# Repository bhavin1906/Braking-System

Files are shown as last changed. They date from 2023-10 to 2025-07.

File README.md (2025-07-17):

# Braking-System
Contributed to the end-to-end development of a Formula Student race car, fully built from scratch in the Team V_locity workshop through extensive design–manufacture–test cycles 

Led the Brakes Department, overseeing system design, component selection, force and thermal calculations, and performance modeling for optimal stopping efficiency under rulebook constraints 

Designed a dual-circuit hydraulic braking system with front–rear biasing, conducted deceleration modeling, brake force distribution analysis, and clamping pressure validation to meet safety-critical standards 

Supervised the manufacture of drilled rotors and caliper assemblies, ensuring reliable water and debris dispersion while maintaining thermal integrity under repeated stress cycles 

Coordinated cross-departmental design integration, working closely with Suspension, Steering, and Ergonomics teams to align brake packaging with upright geometry and ensure seamless mechanical interfacing 

Implemented component-level FEA (Ansys) to verify pedal deflection, disc thermal loads, and mounting stress paths under extreme race conditions 

Managed training programs for junior team members and recruited new talent, organizing multiple hands-on sessions on braking fundamentals, system design, and testing workflows 

Oversaw rigorous testing protocols for every subsystem of the car, ensuring full compliance with Formula Bharat regulations and continuous design iteration based on test data 

Collaborated on chassis–brake–suspension triangulation, optimizing weight distribution and minimizing CG height while balancing driver accessibility and safety envelope 

Participated in core manufacturing processes including arc welding of the AISI 1018 steel chassis, machining of wishbones and knuckles, and hydraulic line routing, gaining firsthand experience in applied fabrication

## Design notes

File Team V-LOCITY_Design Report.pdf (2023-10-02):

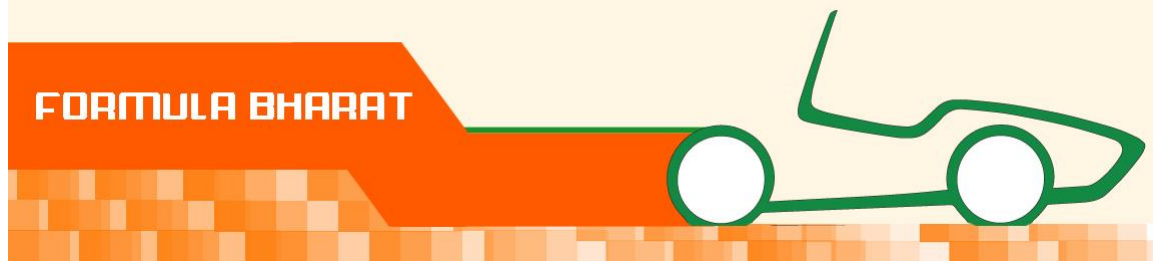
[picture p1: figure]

# FORMULA BHARAT

2021

# DESIGN REPORT

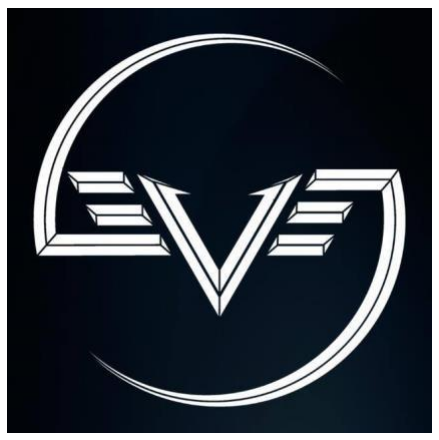
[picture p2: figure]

Team ID | : | 96
Team Name | : | Team V-LOCITY
College Name : | Visvesvaraya National Institute Of
| | Technology
City | : | Nagpur, Maharashtra
Report Author | : | Aishwarya Zawar
Report Co-Author : | Tanmay Kansal

INTRODUCTION

This design report is submitted by Team V-locity from VNIT, Nagpur. Visvesvaraya National Institute of Technology (VNIT) is located in Nagpur and is one of the 31 NITs in the country. The environment in the college coupled with interest of students in automobiles led to the creation of Team V-locity in 2009. Since then the team has been regularly participating in SAE events. The goal of 2021 for Team V-locity, VNIT Nagpur is to design and fabricate a vehicle which embodies innovation and elegance, while ensuring safety. The team was divided into departments, each responsible for the design and the manufacturing of the subassemblies of the vehicle, and the management team for the sponsorship and managerial activities. This report diagnoses the attributes of the vehicle subassemblies, highlighting the considerations, functions and processes behind their design.

Design goals:

The primary goal that was kept in mind while designing was to build a car for the weekend racing event which would have a simple yet innovative structure with optimum space utilization and using simple yet standard manufacturing methods for the manufacturing of the car.

The team having previously participated in SAE Supra 2019, comprehensively scrutinized the previous designs and addressed the grey areas. The suspension system was redesigned and optimized to increase the stiffness and also improve the overall drivability of the car. We have tried to achieve a low center of gravity as well as centralized weight distribution with the placement of components. The components were so placed that be conducive to the driver for ease of access to all the components for future customization and repair. Thus, we were able to come up with a design that would be simple yet efficient and conducive to the weekend racing event.

CHASSIS:

a) Material used-
1. AISI 1018 steel tubes
Reasons-
1. Light weight 2. Cheap 3. Good strength 4. Excellent weldability b) Type of welding-

Arc welding

### 1. Dimensions of members-

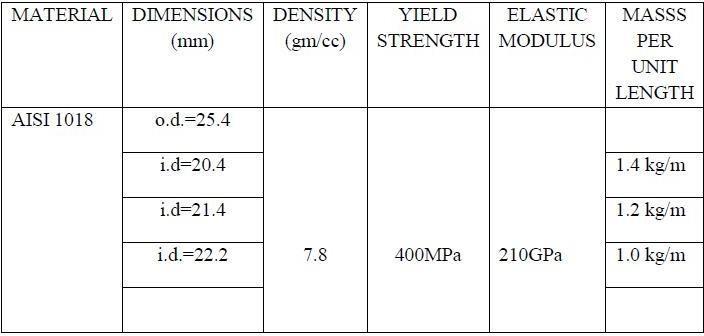
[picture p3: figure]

Rules from rulebook-

1. T2.3 Wheelbase- The car must have a wheelbase of at least 1525 mm (60 inches). The wheelbase is measured from the center of ground contact of the front and rear tires with the wheels pointed straight ahead.

2. Main Hoop- T3.11.4 In the side view of the vehicle, the portion of the Main Roll Hoop that lies above it attachment point to the Major Structure of the Frame must be within ten degrees (10°) of the vertical.
3. T3.11.6 In the front view of the vehicle, the vertical members of the Main Hoop must be at least 380 mm (15 inch) apart (inside dimension) at the location where the Main Hoop is attached to the Major Structure of the Frame.
4. Front Hoop- T3.12.4 The top-most surface of the Front Hoop must be no lower than the top of the steering wheel in any angular position.
5. T3.12.5 The Front Hoop must be no more than 250 mms (9.8 inches) forward of the steering wheel. This distance shall be measured horizontally, on the vehicle centerline, from the rear surface of the Front Hoop to the forward most surface of the steering wheel rim with the steering in the straight-ahead position.
6. T3.12.6 In side view, no part of the Front Hoop can be inclined at more than twenty degrees (20°) from
the vertical.
7. MAIN HOOP BRACING- T3.13.2 The Main Hoop must be supported by two braces extending in the forward or rearward direction on both the left and right sides of the Main Hoop.
8. T3.13.4 The Main Hoop braces must be attached as near as possible to the top of the Main

Hoop but not more than 160 mm (6.3 in) below the top-most surface of the Main Hoop. The included angle formed by the Main Hoop and the Main Hoop braces must be at least thirty degrees (30°).

9. FRONT HOOP BRACING- T3.14.2 The Front Hoop must be supported by two braces extending in the forward direction on both the left and right sides of the Front Hoop.

Side Impact Structural member must connect the Main Hoop and the Front Hoop. With a 77kg (170 pound) driver seated in the normal driving position all of the member must be at a height between 300 mm (11.8 inches) and 350 mm (13.8 inches) COCKPIT- 21. T4.1 Cockpit Opening 22. T4.1.1 In order to ensure that the opening giving access to the cockpit is of adequate size, a template shown in Figure 8 will be inserted into the cockpit opening. It will be held horizontally and inserted vertically until it has passed below the top bar of the Side Impact Structure (or until it is 350 mm (13.8 inches) above the ground for monocoque cars). No fore and aft translation of the template will be permitted during insertion. e) Static and Dynamic Analysis of Roll Cage-

10. T3.14.3 The Front Hoop braces must be constructed such that they protect the driver's legs and should extend to the structure in front of the driver's feet.
11. T3.14.4 The Front Hoop braces must be attached as near as possible to the top of the Front Hoop but not more than 50.8 mm (2 in) below the top-most surface of the Front Hoop.
12. OTHER SIDE TUBE RECQUIREMENT- T3.16 -Other Side Tube Requirements If there is a Roll Hoop brace or other frame tube alongside the driver, at the height of the neck of any of the team's drivers, a metal tube or piece of sheet metal must be firmly attached to the Frame to prevent the drivers' shoulders from passing under the roll hoop brace or frame tube, and his/her neck contacting this brace or tube.
13. Frontal Impact Structure- T3.18.1 The driver's feet and legs must be completely contained within the Major Structure of the Frame. While the driver's feet are touching the pedals, in side and front views no part of the driver's feet or legs can extend above or outside of the Major Structure of the Frame.
14. T3.18.2 Forward of the Front Bulkhead must be an energy-absorbing Impact Attenuator.
15. BULKHEAD- T3.19.2 Except as allowed by T3.19.3, The Front Bulkhead must be located forward of all noncrushable objects, e.g. batteries, master cylinders, hydraulic reservoirs.

16. T3.19.3 The Front Bulkhead must be located such that the soles of the driver's feet, when touching but not applying the pedals, are rearward of the bulkhead plane. (This plane is defined by the forward-most surface of the tubing.) Adjustable pedals must be in the forward most position.

BODYWORK

17. T3.24.1 Sharp edges on the forward-facing bodywork or other protruding components are prohibited.
18. T3.24.2 All forward facing edges on the bodywork that could impact people, e.g. the nose, must have forward facing radii of at least 38 mm (1.5 inches). This minimum radius must extend to at least forty-five degrees (45°) relative to the forward direction, along the top, sides and bottom of all affected edges.
19. T3.25.1 The Side Impact Structure for tube frame cars must be comprised of at least three (3) tubular members located on each side of the driver while seated in the normal driving position
20. T3.25.3 The locations Initial speed of the car = 60 Km/hr.=16.67 m/s

K.E. of the vehicle = .5* (300 Kgs) * sqr.(16.67 m/s)

Total crush energy = .5*(300Kgs)*sqr.(7 m/s) = 7350 J

Net energy after the attenuator has been crashed = 34333.33J

Velocity after crush - KE net = .5*m*sqr.(v)

Thus v= √ (2 KE net/m) = 15.129 m/s.

Assuming time taken for the car to come to rest after crush is .4 sec, deceleration = v/t = 4*g

{Standard value used while designing cars}

Assuming final mass of car = 300 kg, total force = 300*4*g = 11.77 kN

For Optimum testing of design taking,

Factor of Safety = 1.7

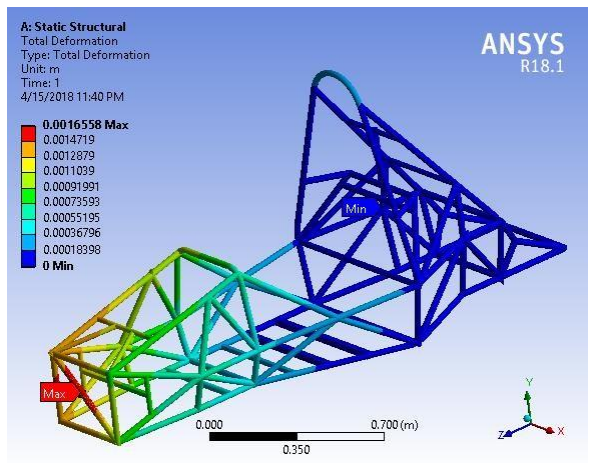
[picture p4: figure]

Force F = 20000 N

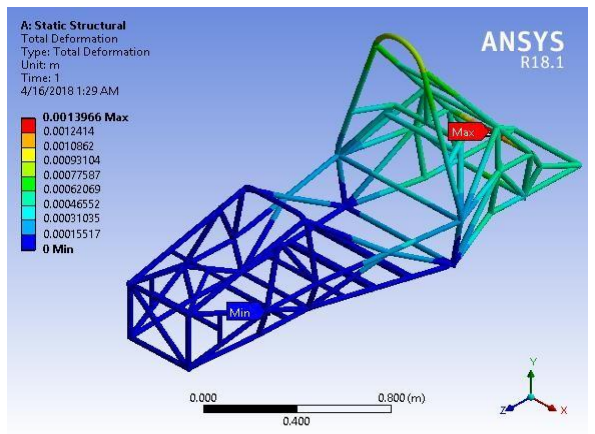
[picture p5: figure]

1.Front Impact : | 2. Rear Impact:

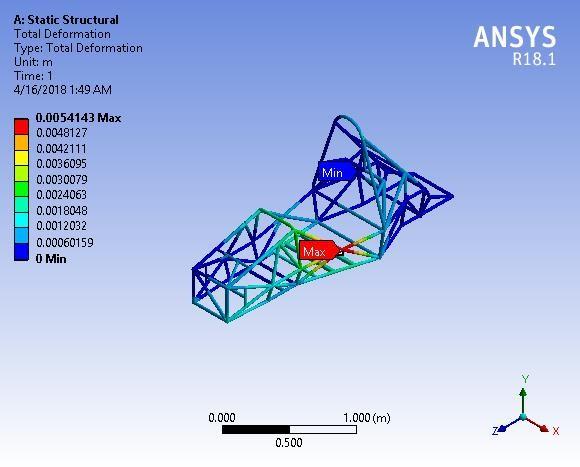
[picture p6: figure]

### 3. Side Impact:

SUSPENSION system:

Type of Suspension - Pushrod Suspension

Pushrod suspension gives more stiffness to our vehicle than previous type of suspension (McPherson strut) used in our last vehicle.
The suspension was designed to reduce the sprung mass, give stable characteristics such as camber change, roll centre and to minimize bump steer. For this, the last year’s suspension was analysed. We were able to save weight in knuckle, adapter plate and wishbone arms. The push-rod system is used, which allows us to change spring constant if necessary and also solves the problem of buckling which occurs in the case of simple spring system. The toes and camber of vehicles is kept to zero. Kingpin angle of 5 degrees is provided by structure of upright.
The team followed the following process steps:
a) Wheel selection
b) Tire selection
c) Wheelbase and track selection
d) Ground clearance optimization
e) Roll center optimization
f) Steering consideration
g) Braking considerations
h) All forces considerations
i) Packaging
Short long arm suspension geometry was used which helped us to minimize camber change. It also helped us in optimizing roll center height and keeping it almost at the same location with respect to car. Roll centre height was calculated considering, under-steer, non- toppling condition and reduction in scrub, using following formula. R*t = F*(roll center-center of mass) R= weight transfer due to roll
Track width rear= 1200mm
Track width front= 1300mm
Fc = Centrifugal Force= 0.7mg
Also change in roll center height is kept small so that roll properties of the vehicle do not change drastically under rolling condition. According to these roll center calculations, four bar chains were sketched for front and rear suspension. Force analysis of the four-bar chain was carried out by applying maximum reaction force on the knuckle, F= 1428N for front & F= 1668N for rear.
Using this force analysis, forces in the pull-rods were calculated. Using this pull-rod force and spring stiffness, k=45000 N/m (Bajaj avenger), bell cranks were designed (Arm ratio: 6:8 (for front suspension) and 6.5:10 (for rear suspension)) . Knuckle was designed with mountings for wishbones, tie rod, and brake caliper & brake adaptor plate. We also took care of packaging because it is a part which contributes to most of air drag by suspension components and weight. It was then analyzed with following forces-
1. Reaction force due to weight of car: Front= 941.4N , Rear= 1412.6 N
2. Braking torque= 100 N.m
3. Force due to acceleration= 507.1N
Wishbones were designed to keep the stresses under maximum stress value= 157.4 MPa, considering factor of safety, welding and stress reversal factor.

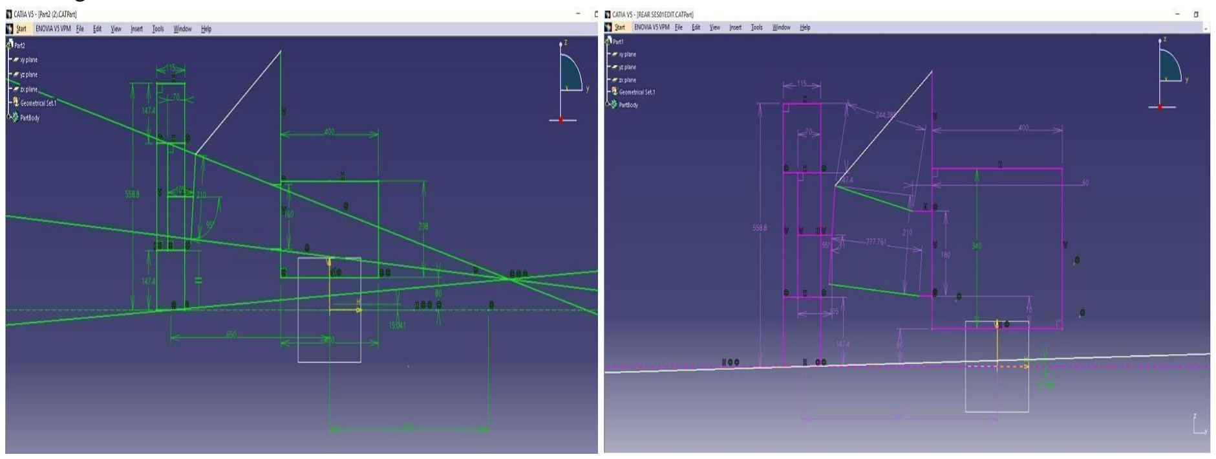
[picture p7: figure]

Front Suspension Calculations X= Force through upper wishbone
Y= Force through pushrod
Z= Force through lower wishbone
FC = Centrifugal Force | = 1318.46 N
R = Reaction Force by ground = 941.4 N
Bell Crank Ratio - Pushrod : Spring = 6:8
Applying Force and Moment Balance,
X*sin(13.4) + Y*sin(40) + Z*sin(4.32) = 941.4 N
-X*cos(13.4) + Y*cos(40) - Z*cos(4.32) = 1318.46 N
X*cos(13.4)*(0.411) + Z*cos(4.32)*(0.147) - Y*cos(40)*(0.384) + Y*sin(40)*(0.044) = 0 Solving these equations, we obtain
X = 500.2 N
Y = 1366.68 N
Z = -759.89 N
Therefore, Force transmitted through spring = 1366.68 * (6/8) N= 1025.01 N Deflection required in the spring for that force = 5 cm
Therefore Spring Constant (k) = 1025.01/0.05= 20502 N/m
We have used a spring having spring constant 45000N/m
So, Factor of Safety = 45000/ 20502= 2.19

Rear Suspension Calculations
X= Force through upper wishbone
Y= Force through pushrod
Z= Force through lower wishbone
FC = Centrifugal Force | = 1977.69 N
R = Reaction Force by ground = 1412.64 N Bell Crank Ratio - Pushrod : Spring = 6.5:10 Applying Force and Moment Balance,

X*sin(12.765) + Y*sin(47.6) + Z*sin(5.122) = -1977.69 N
X*cos(12.765) + Y*cos(47.6) - Z*cos(5.122) = 1412.64 N
X*cos(12.765)*(0.384) + X*sin(12.765)*(0.044) + Z*cos(5.12)*(0.147) + Z*sin(5.122)*(0.025) - Y*cos(47.6)*(0.384) + Y*sin(47.6)*(0.044) = 0
Solving these equations, we obtain
X = 2100.53 N, Y = 1639.03 N , Z = -2932.81 N
Therefore, Force transmitted through spring = 1639.03 * (6.5/10) N = 1065.369 N Deflection required in the spring for that force = 5 cm
Therefore, Spring Constant (k) = 1065.369/0.05 = 21307 N/m
We have used a spring having spring constant 45000N/m
So, Factor of Safety = 45000/ 21307 = 2.11

Wheel Assembly:

WHEELS AND TYRES

Tire selection is always a critical issue in race car. This year we are keeping same tire and alloy wheels used in former car. Reasons are, 145 width tires are sufficiently wider to give traction for a car having 37 bhp engine. For such engine cars large width tires reduce the fuel economy of the car along with increase in frictional and rolling resistance. Large tires and alloy wheels increases the car weight largely due to the reinforcement in rims. Also, considering rain chances on race track, we are keeping treaded tires instead

of slick tires. Further low width and treaded tires are ideal for front wheels for better steering maneuverability. Treads reduce the tire slip angle and hence Ackermann geometry closely holds the real steering geometry.

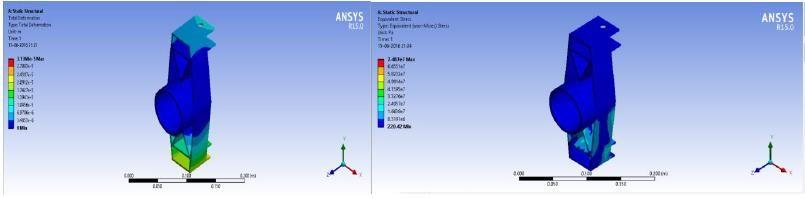
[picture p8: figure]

Upright Analysis

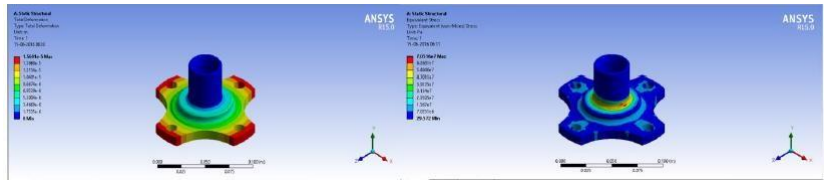
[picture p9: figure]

Hub Analysis

STEERING system:

Rack and Pinion steering system has been chosen over other steering systems for its compactness and ease of adjustment in Ackermann. The minimum width of the autocross track has been specified to be 3.5m and the outside diameter of the sharpest turn is 9m. Using these values, the calculations on SOLIDWORKS gave the angles of the front wheels to produce no scrub to be 39.81° for inner wheel and 27.24° for outer wheel. (fig)

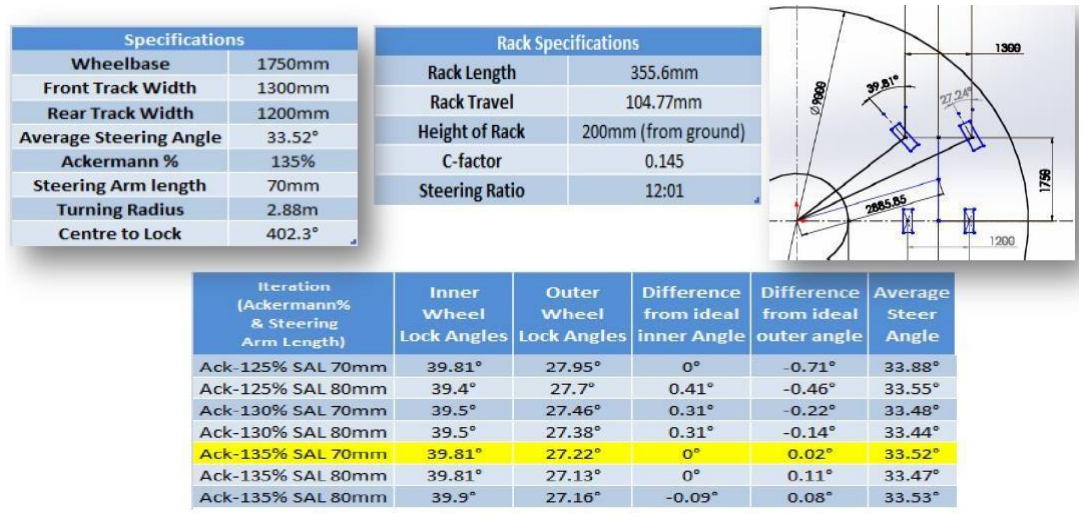
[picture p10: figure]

- From the above iterations, simulated on CATIA, at 135% Ackermann and for steering arm length of 70mm we get the best possible steering lock angles for both the wheels to keep scrub at minimum.
- The turning radius of the centre of the car comes out to be 2.88m which is within the limits presented by the earlier model.
- The steering arm is mounted 77.4mm from the bottom of the knuckle to reduce bump steer and the analysis is done on CATIA

BRAKES:

Brakes Calculations-Assumptions made
1) Car weight = 400kg
2) Wheel base = 1700mm
3) Force distribution (front to rear) = 6:4
4) Stopping distance = 5m
5) Speed of car = 40km/hr
6) Coefficient of friction between tyre and road = 0.8
7) Tyre radius = 0.25m
8) Disc radius = 10cm
9) Coefficient of friction between pads and disc = 0.4
10) Calipers piston diameter = 1 inch
11) Master cylinder piston diameter = 18mm
12) Pedal ratio = 39:11
13) Front static load = 1600N
14) Rear static load = 2400N
15) Height of CG = 0.3m

Procedure of calculation
W=weight, m=mass, b=distance of C.G. from front tyre, c=distance of C.G. from rear tyre, L=distance between tyres. For stopping distance 5m and for initial velocity 40km/hr
v2=u2+2ds

Where, v=final velocity, u= initial velocity, d=deceleration, s= stopping distance d=u2/2s
d=11.122/2*5 =12.36 m/s2
deceleration ratio = 1.26g
1) Dynamic loads = W=m((c/L)+(Ax/g)(h/L)
Front dynamic weight =1600+ [(1.26*0.3*400*9.81)/1.7]= 2472.5 N Rear dynamic weight =2400-(1.261*0.3*400*9.81)/1.7)=1527.5N
2) F=Wf*g*μ
Total front dynamic force = 2472.5*0.8 = 1978N
Total rear dynamic force = 1527.5*0.8 = 1222N
3) Front braking force on single tyre = Ff= 1978/2 = 989N Rear braking force on single tyre = Fr= 1222/2 = 611N
4) T= F*r
Braking torque for single front tyre =989*0.25= 247.25Nm
Braking torque for single rear tyre = 611*0.25 =152.75Nm
5) Frictional force of single disc of front wheel=Fdf= 247.25/0.10=2472.5N Frictional force of single disc of rear wheel = Fdr= 152.75/0.10=1527.5N
6) Clamping force on single disc of front wheel = Fclamp=2472.5/0.4=6181.25N Clamping force on single disc of rear wheel=1527.5/0.4 = 3818.75N
7) Force given by M.C on one side caliper for front wheel =
Fcalfront=6181.25/2= 3090.625N
Force given by M.C on one side caliper for rear wheel = Fcalrear=3818.75/2= 1909.375N
8) Pcal=( Fcal/Acal)
Pressure for the front braking circuit=3090.625/0.5*10-3= 6.18MPa
Pressure for the rear braking circuit =1909.375/0.5*10-3=3.81MPa
9) Pcal=Pmc
Force of circuit = (Pmc*3.14*d2)/4
Force required for front braking circuit=6.18×106*3.14*0.0092/4 =393.15N Force required for the rear braking circuit=3.81×106*3.14*0.0092/4 =242.4N Total braking force for the Braking =393.15+242.4=635.55N
As the paddle ratio is 4:1 so,
10) Paddle effort taken by driver =635.55/4 =160N
11) Stopping time: We have v2=u2+2ds & v=u+dt Rearranging the terms we get t=2s/u= (2*5)/11.12=0.899=0.9sec

Braking Mechanism:
1) The braking system has two separate hydraulic circuits arranged in H-type arrangement to ensure braking in case any one of the circuit fails.
2) The brake rotors are drilled in order to make sure that the water or any debris from brake pads
is removed. Thus, leaving the braking efficiency unaltered.
3) The Pedal ratio is taken as 39:11. This pedal ratio actuates sufficient force on the brake disc in order to bring it at rest. And thus proves useful in severe braking condition.

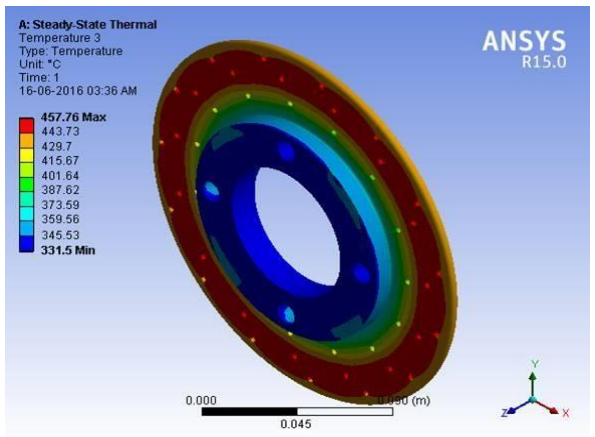
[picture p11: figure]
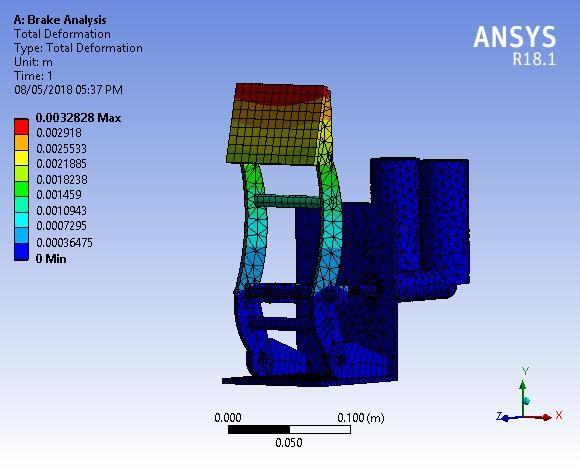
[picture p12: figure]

1. Brake pedal analysis | 2. Temperature Distribution in brake disc

ENGINE SELECTION:
The engine selected for the car is of bike KTM Duke 390. Specifications: Max Torque= 35Nm at 7250rpm, 373.2cc, Single Cylinder 4 stroke liquid cooled engine (Max power 43HP at 9000rpm). Design Considerations: A reliable, safe and efficient drivetrain is desired. A good acceleration is desired with max velocity to be around 105 kmph. Engine is being used as a semi stressed member so that the vibrations are dissipated into the chassis to increase roll cage stiffness. ELECTRONIC SYSTEM:
Before installing the engine into the car, all redundant ECU units were removed from it. Following are the important Electrical Units which are used in the car:
1. Wire harness/connectors
2. Dashboard panel
3. Kill switches
4. Fuses
5. Brake light bulb
6. Battery
7. Starter button
8. Brake Fuel Indicator
INTAKE AND EXHAUST:
- INTAKE SYSTEM
A venturi is designed such that minimum c/s diameter of the air passage is 20 mm. Appropriate flow analysis is done to find out the diverging and the converging angles of the venturi which are 6 and 12 degrees respectively. Intake manifold was added to optimize the efficiency and performance of the engine.
- EXHAUST SYSTEM
Exhaust system was designed according to rulebook. It was designed with objective of reducing noise level while keeping back pressure low. It was ensured that any component of exhaust did not touch any other components of car. ❖ ENGINE SUBASSEMBLY
- FUEL SYSTEM
Fuel tank is designed according to the space available and simplicity in manufacturing. Minimum possible volume is selected taking it to be 4 liters. Placement of Fuel tank is done considering the lowering of CG. Considering the rulebook, proper safety arrangements including belly pan, catch tank, fuel level indicator, filler neck height are used.
- COOLING SYSTEM
For engine cooling purpose single radiator with a larger surface area and the proper piping is used to increase the cooling capacity in order to cater to the demands of an increased load on the engine. The radiator is mounted sideways inside the ducts of the body so as to get maximum expose to the airflow. Also one fan is provided at the back of radiator to insure proper cooling.

DRIVETRAIN:
TYPE OF TRANSMISSION USED AND ITS REASON
Chain Drive is used for transmission, since it is readily feasible for the engine selected. Following calculations were done to find out sprocket dimensions and chain length:
1. Sprocket dimensions (to find secondary ratio):
Let N be the secondary ratio.
Equating> (initial torque on wheels considering static friction) = (initial torque on engine)
μmgR = T* (prim ratio)*(1st gear ratio)*N*(efficiency) | (a)
Values taken: μ=1 (dry road), m=320kg (car+driver), Rwheel=13in=0.325m, Prim ratio=8/3, 1st gear ratio=8/3, Efficiency=0.8 (assumption).
T is calculated from foll:-
T=P1+P2*(2πN/60)+P3*(2πN/60)2
where, P1=(Pmax)/ K=35.18, P2=(Pmax)/ K2=0.035 , P3=(Pmax)/K3 =3.55*10-5 and K=(2 πNp)/60 Here Pmax=35kW, Np=9500 rpm, Putting above values, T=44Nm Equation (a) becomes => 1019.2=250*N N=4 Sprocket diam=3.5*4=14mm Pitch comes out to be p=15.87mm

### 2. Chain Length

Assuming sprocket to sprocket dist=25cm=250mm,
No of links= Ln=2*(250/15.87)+(15+60)/2+(60-15)/2π+(15.87/250)=76.23≈76
Chain length= Ln*p =76*15.87= 1209mm ≈120cm
Chain sprocket and chain are selected that of KTM Duke 390 since the dimensions of them match with the required dimensions as calculated.
- Gear Transmission: 6 speed gearbox of KTM Duke 390
- Differential: Open differential gearset is used.
- Clutch System: Hydraulically actuated clutch is used.
- Axle: Consists of C V Joints Rzeppa.- 2 fixed ,2 plunging Ergonomics:
- Cockpit layout has been constructed considering the driver comfort.
- Prototype roll cage was built to understand drivers comfort position, seat arrangement and steering wheel alignment. Driver position have been made as low as possible to lower the CG of the vehicle.

Safety:

IMPACT ATTENUATOR DATA - Design Selection

From the above matrix clearly, Honeycomb is the better choice for us. Also, its light weight and low price make the material appealing in that it has the ability to be created relatively cheap and also easily replaced.

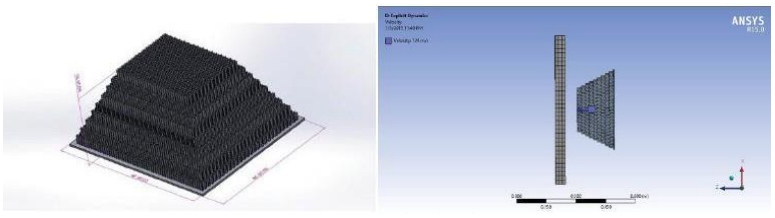
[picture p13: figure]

1.Honeycomb Pyramid Solid Model | 2. Ansys test setup

Calculations:

Vehicle of mass 300kg is impacted with velocity of 7m/s.

So, its K.E. will be (M+m) *v²
/2,

where m is the mass of Impact Attenuator and M is the mass of vehicle,

K.E. = 0.5* (300+0.954) * (7)² = 7373.373J

Impact attenuator is expected to absorb minimum this amount of energy.

Finite Element Analysis

Analysis was performed in the Ansys Explicit Dynamics. Initial testing on the models often failed or was unable to finish due to the complexity of the honeycomb pyramid structure. Our Team created a replacement part for the honeycomb that could be used in the finite element testing. The component had the mechanical properties of the honeycomb yet was modelled as a solid block. This solid block was used for testing in Ansys.

Mechanical properties of Honeycomb replacement solid block:

Test Setup in Ansys: The Impact Attenuator was allowed to impact on the rigid wall at velocity of 124m/s. v= (K.E. x 2/ m)^0.5 ,m=mass of impact attenuator The impact scenario is such that the vehicle collides with the wall with IA in the front and Impact attenuator is expected to absorb all the K.E. But the connectors are not possible in Ansys explicit dynamics. So the Impact Attenuator is given the whole K.E. which gives the above calculated velocity for test.

Property Value Units:

Elastic Modulus 71,000 N/mm^2 | Poisson’s Ratio .3
Shear Modulus 440 N/mm^2 | Density 8.32 x 10-5 g/mm^3
Tensile Strength 290 N/mm^2 | Compressive Strength 4.6 N/mm^2

Yield Strength 268 N/mm^2

Test Results: Impact Attenuator was found to absorb 7458J of energy which complies with the rules

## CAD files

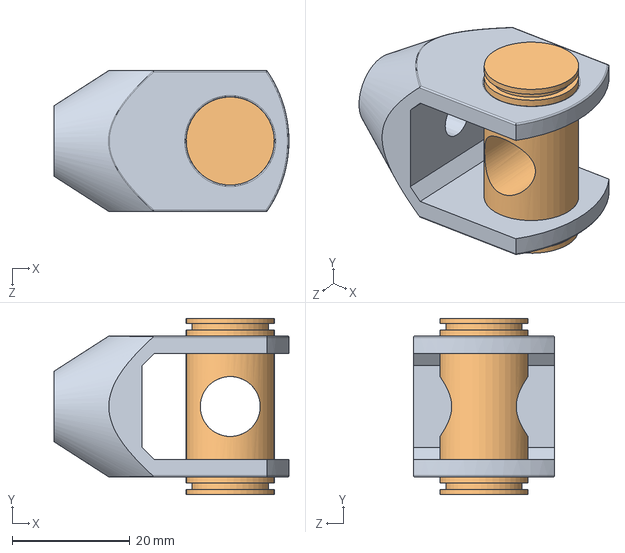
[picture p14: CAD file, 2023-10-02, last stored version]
SolidWorks File/Pedal box/balance bar pivot assembly.SLDASM
40.0 x 30.0 x 24.0 mm
balance bar pivot eye
balance bar pivot

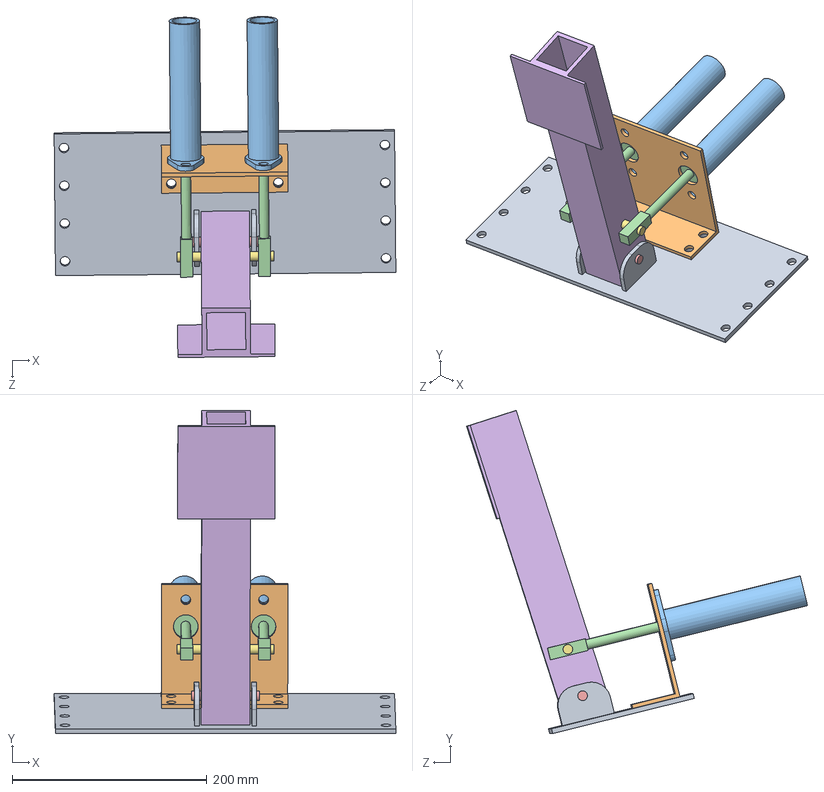
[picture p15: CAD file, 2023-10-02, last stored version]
SolidWorks File/Pedal project/master cylinder assembly.SLDASM
351.4 x 332.1 x 350.6 mm
Bottom Plate
master cylinder mounting
master cylinder x 2
master cylinder_plunge x 2
Bottom pin
Pedal For submission
Pushrod Pin

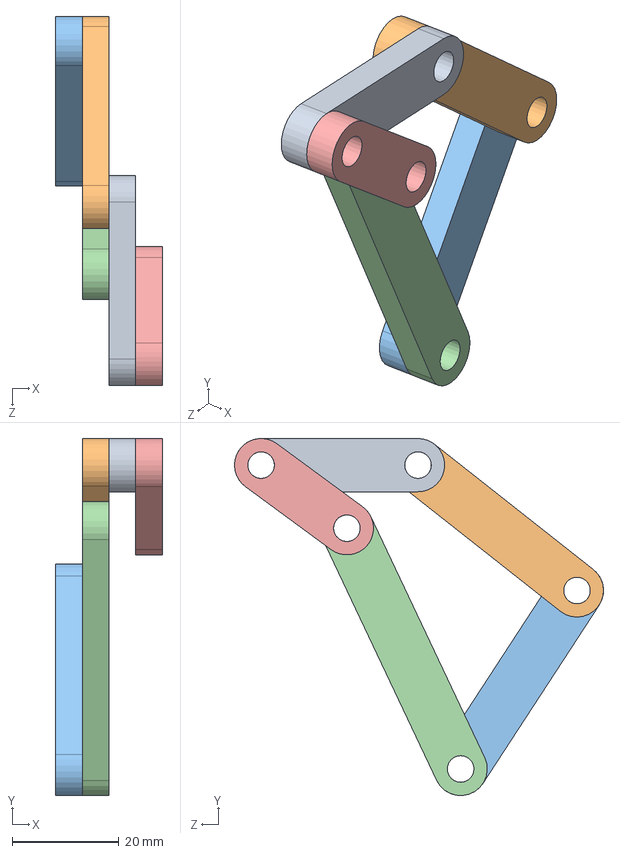
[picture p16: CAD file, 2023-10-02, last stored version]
SolidWorks File/Pedal project/Assem2.SLDASM
20.0 x 67.0 x 69.3 mm

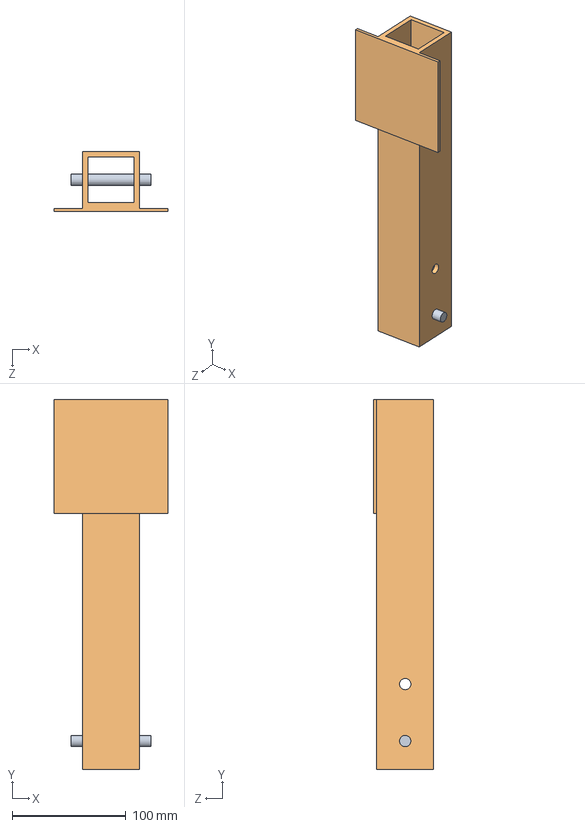
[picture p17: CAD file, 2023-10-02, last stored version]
SolidWorks File/Pedal project/Pedal with pin assembly.SLDASM
100.0 x 325.0 x 53.0 mm
Bottom pin
Pedal For submission

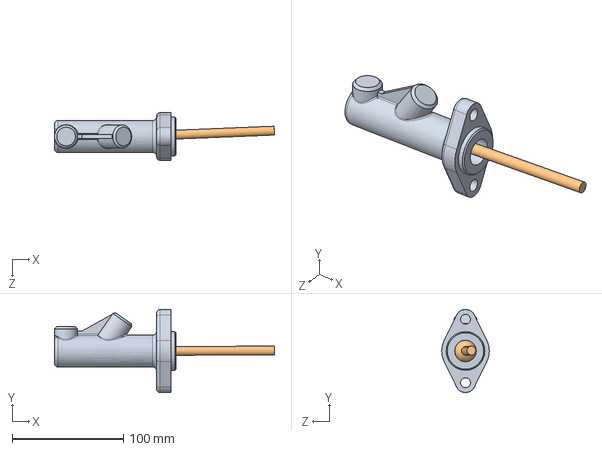
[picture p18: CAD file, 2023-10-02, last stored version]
SolidWorks File/Pedal box/MASTER CYLINDER.SLDASM
198.1 x 74.9 x 42.9 mm
master cylinder housing
master cylinder piston

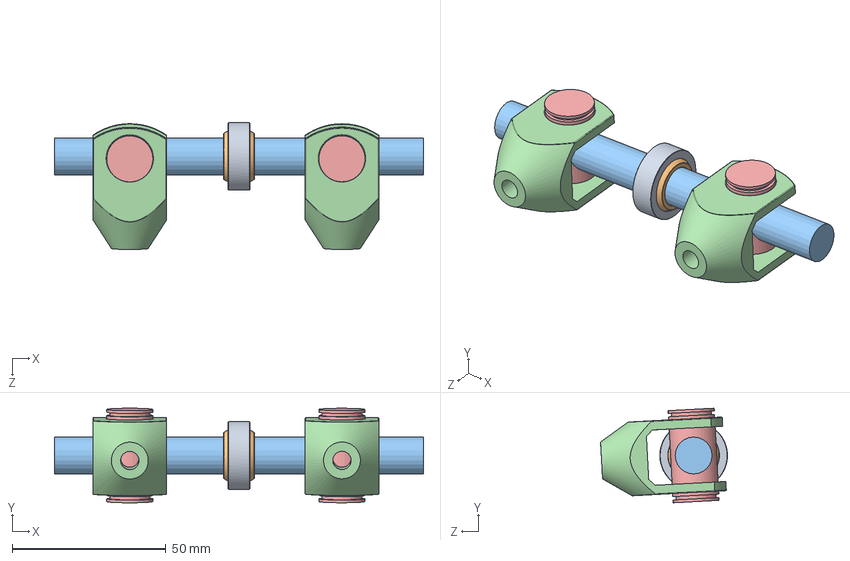
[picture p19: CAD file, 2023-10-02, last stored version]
SolidWorks File/Pedal box/BALANCE BAR.SLDASM
120.0 x 30.8 x 41.3 mm
outter GE12C
inner GE12C
balance bar shaft
balance bar pivot eye x 2
balance bar pivot x 2

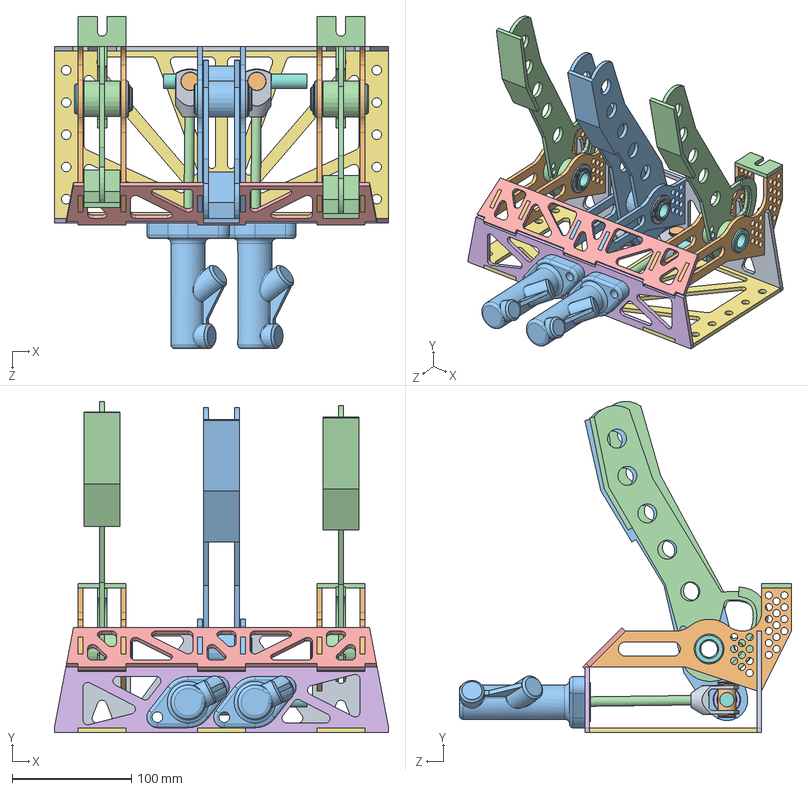
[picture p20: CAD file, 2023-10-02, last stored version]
SolidWorks File/Pedal box/PEDAL BOX.SLDASM
280.0 x 277.4 x 278.0 mm
base back
base gas and clutch sides x 4
base brake sides x 2
cable holder x 2
base top
base front
base bottom
Bearing pin x 3
washer x 3
20mm circlip x 3
brake pedal
gas and clutch pedal x 2
neddle bearing HK2030 x 3
outter GE12C
inner GE12C
balance bar shaft
balance bar pivot eye x 2
balance bar pivot x 2
master cylinder housing x 2
master cylinder piston x 2

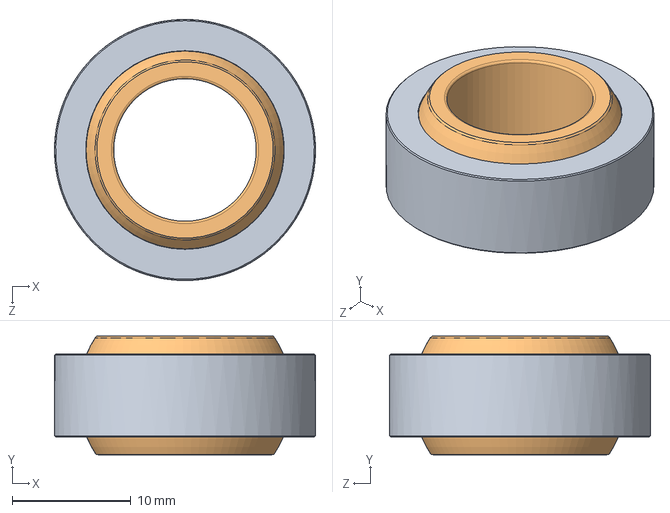
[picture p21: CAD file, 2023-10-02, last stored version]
SolidWorks File/Pedal box/GE 12 C.SLDASM
22.0 x 10.0 x 22.0 mm
outter GE12C
inner GE12C

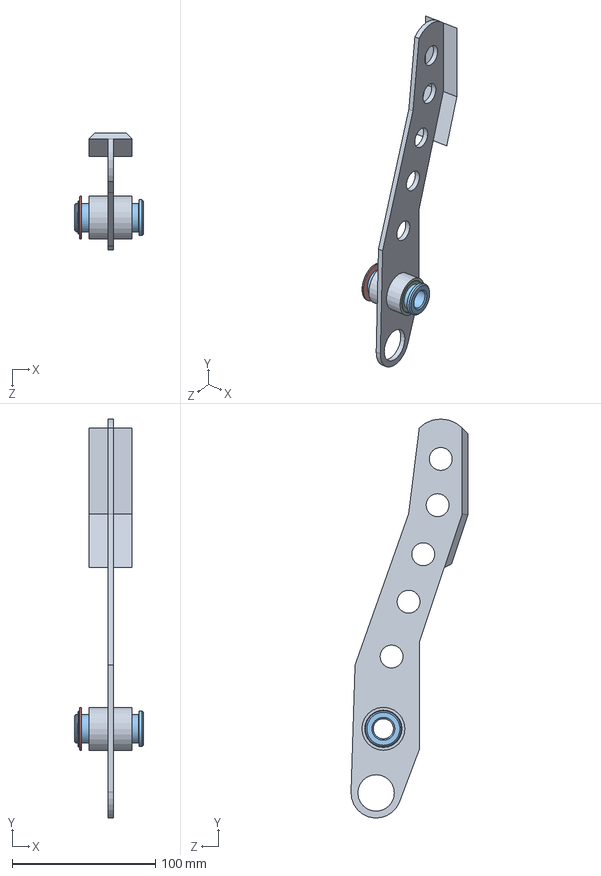
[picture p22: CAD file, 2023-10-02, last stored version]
SolidWorks File/Pedal box/pedal assembly.SLDASM
48.0 x 278.1 x 81.5 mm
gas and clutch pedal
20mm circlip
Bearing pin
neddle bearing HK2030
washer

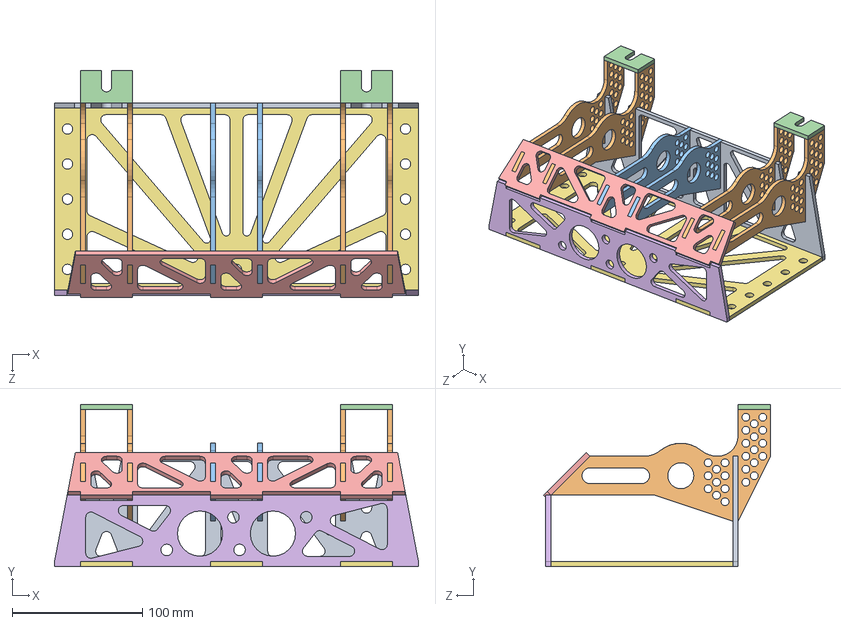
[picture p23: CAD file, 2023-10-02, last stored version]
SolidWorks File/Pedal box/BASE ASSEMBLY.SLDASM
280.0 x 125.0 x 174.7 mm
base back
base gas and clutch sides x 4
base brake sides x 2
cable holder x 2
base top
base front
base bottom

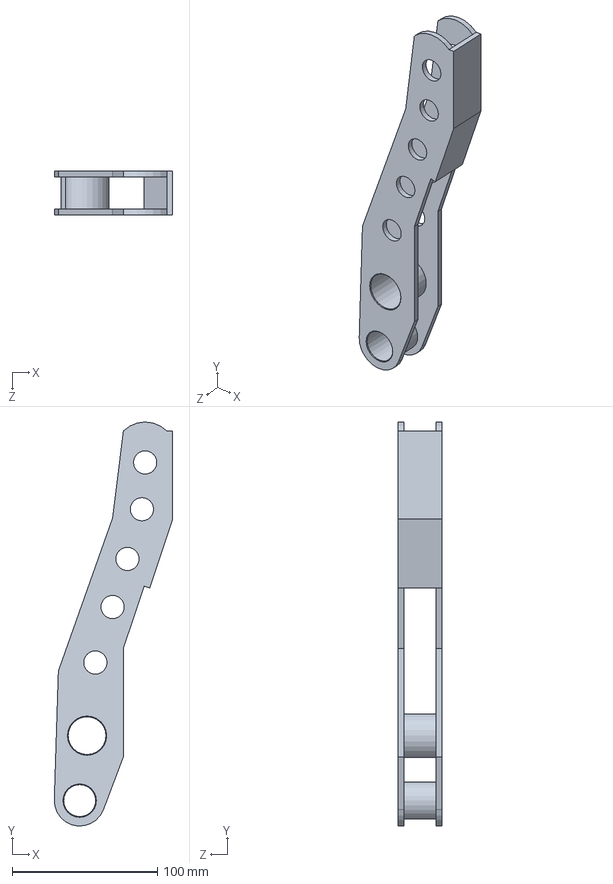
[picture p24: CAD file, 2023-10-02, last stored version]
SolidWorks File/Pedal box/brake pedal.SLDPRT
81.5 x 278.1 x 30.0 mm

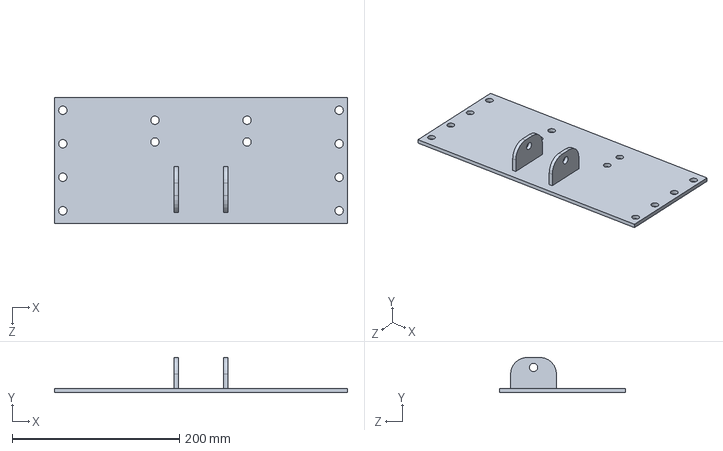
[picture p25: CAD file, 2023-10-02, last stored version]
SolidWorks File/Pedal project/Bottom Plate.SLDPRT
350.0 x 42.0 x 150.0 mm

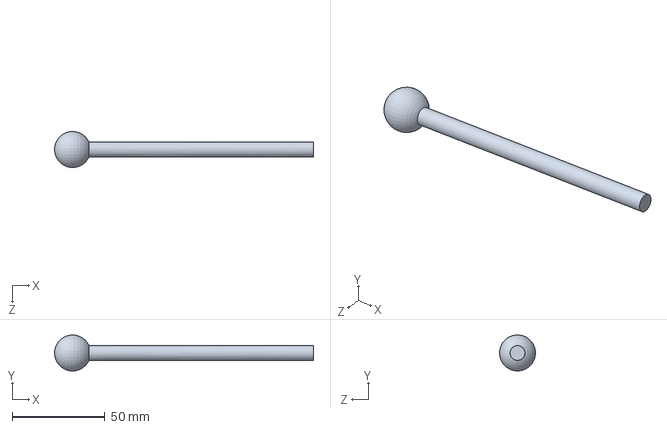
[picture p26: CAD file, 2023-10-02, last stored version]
SolidWorks File/Pedal box/master cylinder piston.sldprt
139.8 x 19.4 x 19.4 mm

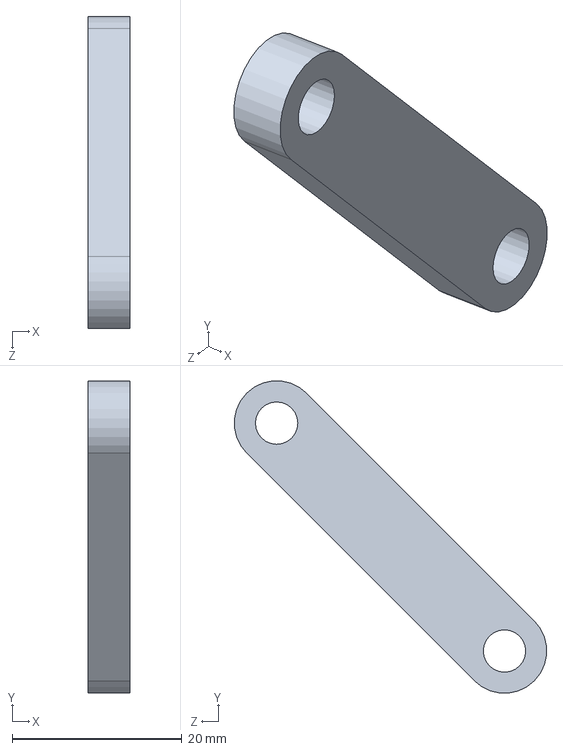
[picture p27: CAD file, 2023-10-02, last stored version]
SolidWorks File/Pedal project/Part4.SLDPRT
5.00 x 36.8 x 36.8 mm

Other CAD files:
SolidWorks File/Pedal box/cable holder.SLDPRT
SolidWorks File/Pedal project/master cylinder.SLDPRT
SolidWorks File/Pedal project/Part5.SLDPRT
SolidWorks File/Pedal project/Part2.SLDPRT
SolidWorks File/Pedal box/20mm circlip.SLDPRT
SolidWorks File/Pedal box/Base.SLDPRT
SolidWorks File/Pedal box/Bearing pin.SLDPRT
SolidWorks File/Pedal box/M12 sipka.SLDPRT
SolidWorks File/Pedal box/balance bar pivot eye.SLDPRT
SolidWorks File/Pedal box/balance bar pivot.SLDPRT
SolidWorks File/Pedal box/balance bar shaft.SLDPRT
SolidWorks File/Pedal box/base back.SLDPRT
SolidWorks File/Pedal box/base bottom.SLDPRT
SolidWorks File/Pedal box/base brake sides.SLDPRT
SolidWorks File/Pedal box/base front.SLDPRT
SolidWorks File/Pedal box/base gas and clutch sides.SLDPRT
SolidWorks File/Pedal box/base top.SLDPRT
SolidWorks File/Pedal box/gas and clutch pedal.SLDPRT
SolidWorks File/Pedal box/inner GE12C.SLDPRT
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
